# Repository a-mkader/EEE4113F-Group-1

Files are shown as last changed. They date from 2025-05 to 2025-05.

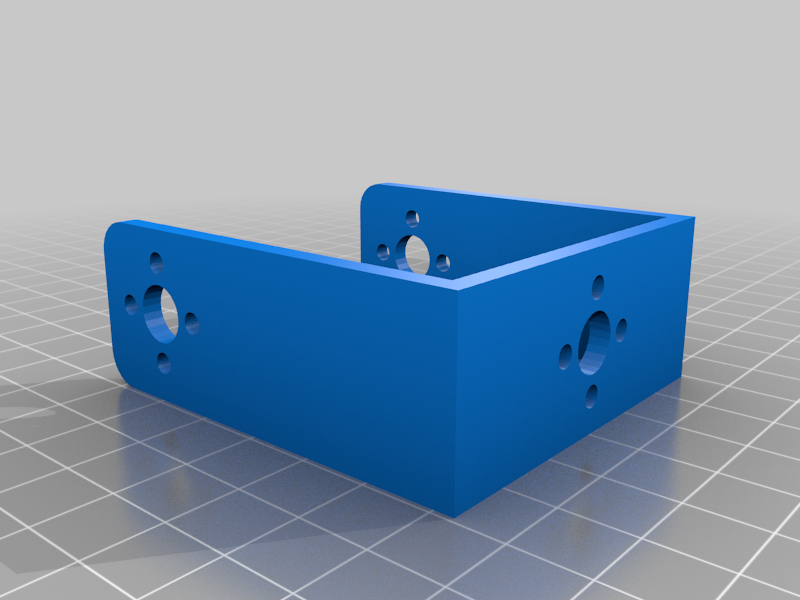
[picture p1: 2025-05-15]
Camera Tracking and Visual Deterrent/3D Designs/PAN-TILT SERVO MG995 - MG996 - DS3218 - 3458238/images/cf411c098905289544de61feb33862b2.png

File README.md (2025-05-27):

# 🐧 Humane Honey Badger Deterrent System  
**EEE4113F Final Year Project – Group 1 (2025)**  
University of Cape Town – Department of Electrical Engineering

## 📋 Overview

This repository contains the full implementation of a humane, AI-assisted deterrent system developed to protect endangered African penguins from honey badger predation. The project was completed as part of the EEE4113F Final Year Design course.

The system integrates real-time animal detection, a web-controlled tactile deterrent, and a visual tracking subsystem, all deployed on low-power, field-ready hardware.

---

## 🧠 Subsystems

### 1. Sensing & Identification 
- Passive infrared (PIR) sensors trigger image capture.
- A 5MP IR camera captures images upon motion detection.
- A TensorFlow Lite model classifies the image into:
  - `honey_badger`, `penguin`, `background`, or `other`
- Upon detecting a honey badger, a GPIO pin is triggered to activate deterrents.

### 2. Tactile Deterrent + Web UI 
- Raspberry Pi-controlled solenoid spray mechanism.
- React-based frontend and Flask backend.
- Features:
  - Manual calibration
  - Livestream from Pi camera
  - Log of past deterrents
  - Weather widget for ranger awareness

### 3. Visual Tracking Subsystem
- Pan-tilt servo system controlled by Raspberry Pi.
- Face detection via OpenCV.
- Flashing light deterrent to startle predators.
- Designed to enhance precision and reduce habituation.

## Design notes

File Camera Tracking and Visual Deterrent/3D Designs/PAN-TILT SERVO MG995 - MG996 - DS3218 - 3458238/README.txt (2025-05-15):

PAN-TILT SERVO MG995 - MG996 - DS3218 by VICTORHP7 on Thingiverse: https://www.thingiverse.com/thing:3458238

Summary:
PANT-TILT compatible with servos MG995 - MG996 - DS3218It works smooth!M310 screws are recommended. M312 will do it too.

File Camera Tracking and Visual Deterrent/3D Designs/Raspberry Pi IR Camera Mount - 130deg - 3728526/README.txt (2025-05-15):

Raspberry Pi IR Camera Mount - 130deg by Douglas_K on Thingiverse: https://www.thingiverse.com/thing:3728526

Summary:
This is borne of my not wanting to have a light on in the room when I'm printing.  So, I'm running an infrared camera with it's own lighting.  This is the one I used:Raspberry Pi 3 Night Vision Fisheye Camera 5MP OV5647 130 Degree Focal Adjustable Camera for Raspberry Pi 3 Model B Plushttps://www.aliexpress.com/item/32932807062.htmlThe main design I based this on, "Raspberry Pi IR Camera Mount" by MonkeyBear", had the correct openings for the lights, but they were too far apart.  A bit of a remix fixed that.  Then I used a bit from the "T-slot V-slot Universal camera mount :CR10, tevo tornado, ender 3 logitech c270 c920, picamera, gopro, action camera , prusa mk3, others" to add the mounting bit that's compatible with the bed mount I use with my Ender 3 Pro, "Ender 3 bed camera mount logitech c270,pi camera,gopro,action camera, holder(BETA TESTING finished)"It works a treat, as the 2nd image shows.:)This mount connects with this mount system which works well with the Creality Ender 3: https://www.thingiverse.com/thing:2999957

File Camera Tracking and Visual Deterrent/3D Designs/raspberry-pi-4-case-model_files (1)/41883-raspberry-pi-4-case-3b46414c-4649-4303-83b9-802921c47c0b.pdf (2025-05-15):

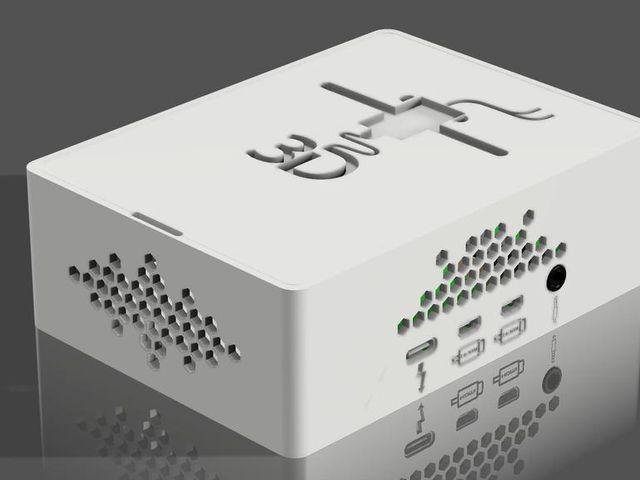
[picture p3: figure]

6.83 hrs

2 pcs

f

0.20 mm

k

0.40 mm

h

PLA

78 g

d

Prusa MINI /

MINI+

# Summary

A RaspBerry Pi 4 case designed to optimize the airflow around the board

and to keep it well cooled without the need of...

3D Printers (https://www.printables.com/model?categoryId=1) | > | Accessories (https://www.printables.com/model?categoryId=40)
Tags: case | raspberry | octoprint | octopi | 3dprinter
raspberrypi | raspberrypicase | octoprintcase

A RaspBerry Pi 4 case designed to optimize the airflow around the board

and to keep it well cooled without the need of a cooling fan.

From the hestetical point of view, it is recommended White PLA, but it can

be printed in any color you prefer.

Hope you enjoy it. If so, thumbs up and happy printing!

JayCee09 (https://www.printables.com/social/92276/about)

# RaspBerry Pi 4 case

VIEW IN BROWSER (https://www.printables.com/model/41883-raspberry-pi-4-case)

updated 12. 4. 2022 | published 9. 10. 2020

# Model files

## Print instructions Category: 3D Printer Accessories Summary

A RaspBerry Pi 4 case designed to optimize the airflow around the board

and to keep it well cooled without the need of a cooling fan.

From the hestetical point of view, it is recommended White PLA, but it can

be printed in any color you prefer.

Hope you enjoy it. If so, thumbs up and happy printing!

## Print Settings

### Rafts: No

### Supports: No

### Resolution: 0.2

## Infill: 25%

### Filament: Anycubic PLA White Notes:

Recommended at least 25% infill for the Lower case. The Upper case

doesn't require specified infill, while the infill for the Case cap is up to you

to decide.

For a better result, four screws M2.5x8 are recommended in order to keep

the board safely in place.

Take a look at these designes too:

Raspberry Pi 4B/Octoprint Honeycomb case da JayCee09 | Scarica il
modello STL gratuito | PrusaPrinters (https://www.prusaprinters.org/it/prints/44108-raspberry-pi-4boctoprint-honeycomb-case)

RaspberryPi 4B/Octoprint case and mount for Prusa MINI da JayCee09
| Scarica il modello STL gratuito | PrusaPrinters (https://www.prusaprinters.org/it/prints/118058-raspberrypi-4boctoprint-case-and-mount-for-prusa-m)

If you like this design, please consider buying me a coffee to support me in

the creation of many other useful designs as a sign of gratitude for the

huge amount of time and effort. Thank you very much and happy printing!

•

•

upper_case.stl

# Print files

h PLA | k 0.40 mm | f 0.20 mm | 1.47 hrs | 22 g | d Prusa MINI / MINI+
h PLA | k 0.40 mm | f 0.20 mm | 5.36 hrs | 56 g | d Prusa MINI / MINI+

Find source .stl files on Thingiverse.com (https://www.thingiverse.com/thing:4562146)

# License

This work is licensed under a

Creative Commons (4.0 International License)

Attribution (http://creativecommons.org/licenses/by/4.0/)

✖ | Sharing without ATTRIBUTION
✔ | Remix Culture allowed
✔ | Commercial Use
✔ | Free Cultural Works
✔ | Meets Open Definition

lower_case.stl

case_cap.stl

case-cap_02mm_pla_mini_1h28m.gcode

upperlower-case_02mm_pla_mini_5h21m.gcode

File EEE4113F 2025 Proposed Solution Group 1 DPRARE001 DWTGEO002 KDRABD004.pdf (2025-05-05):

Solution Statement and Subsystem Breakdown
Solution Statement
This project proposes a humane and integrated deterrent solution designed to protect penguin colonies from honey badgers. The approach combines real-time animal detection, automated species identification, and visual deterrents specifically flashing lights. By activating these visual deterrents only when a honey badger is positively identified, the system ensures minimal interference with penguins. This targeted strategy is intended to eectively discourage honey badger intrusions while maintaining a safe and undisturbed environment for the penguin population.

Subsystem Breakdown
The proposed solution is structured into three complementary subsystems, each managed by a specific team member:

### 1. Sensing Subsystem (Georgene de Wet)

The sensing subsystem will deploy motion detection sensors and thermal cameras strategically positioned along the existing penguin colony fence. The motion detection sensors provide energy-eicient, reliable detection of animal movement. To enhance accuracy, especially during night time or in challenging weather conditions, thermal cameras will detect the presence of animals through their unique heat signatures, reducing the likelihood of false detections due to environmental factors or penguins.

### 2. Software and Identification Subsystem (Arend Jacques du Preez)

This subsystem will be responsible for processing sensor data in real-time to distinguish honey badgers from penguins and other wildlife. Utilizing advanced, lightweight artificial intelligence and machine learning methods suitable for low-power hardware, this subsystem will rapidly and accurately classify the animals detected. Upon positive identification of a honey badger, the software subsystem will promptly signal the visual deterrent subsystem for activation.

### 3. Camera Tracking and Visual Deterrent Subsystem (Abdul-Mateen Kader)

The camera tracking subsystem will continuously track the movements of detected honey badgers outside the protected area, enabling precise targeting of deterrents. Once the presence of a honey badger is confirmed, this subsystem will activate flashing lights to immediately deter the animal. The visual deterrent is designed to provide eective repulsion without adversely aecting the natural behaviours and routines of penguins, ensuring ecological safety and sustained eectiveness.
Together, these subsystems form a comprehensive and humane strategy to eectively protect penguin habitats from honey badger intrusion while prioritizing ecological sensitivity and long-term reliability.

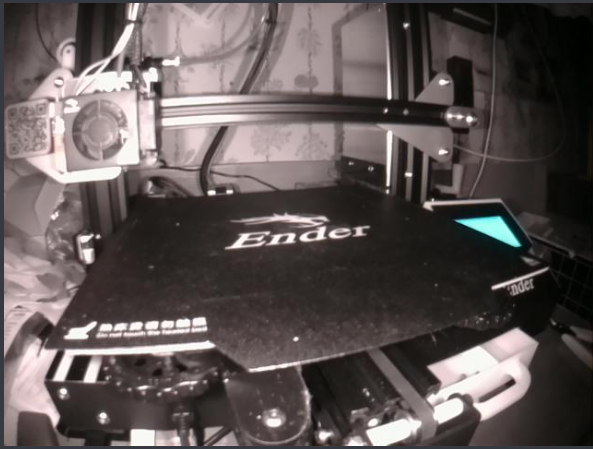
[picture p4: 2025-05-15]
Camera Tracking and Visual Deterrent/3D Designs/Raspberry Pi IR Camera Mount - 130deg - 3728526/images/IR_PiCam_Image.png

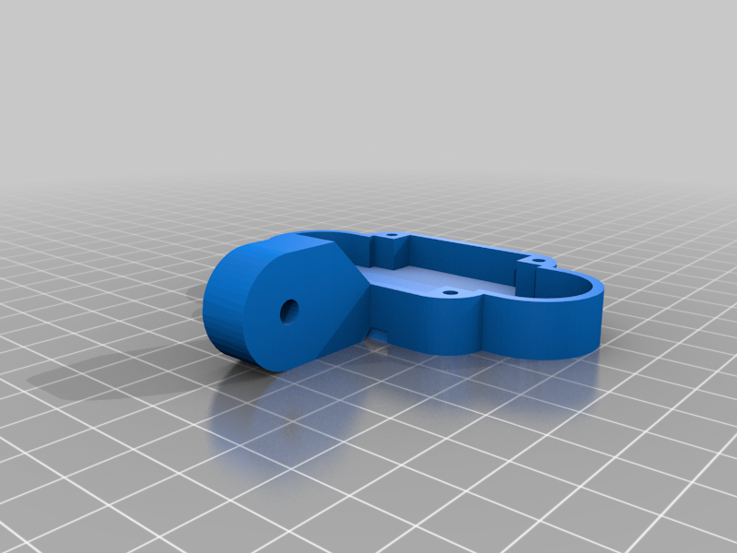
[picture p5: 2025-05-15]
Camera Tracking and Visual Deterrent/3D Designs/Raspberry Pi IR Camera Mount - 130deg - 3728526/images/b11e25e2dc768ef985b8156a6ab60719.png

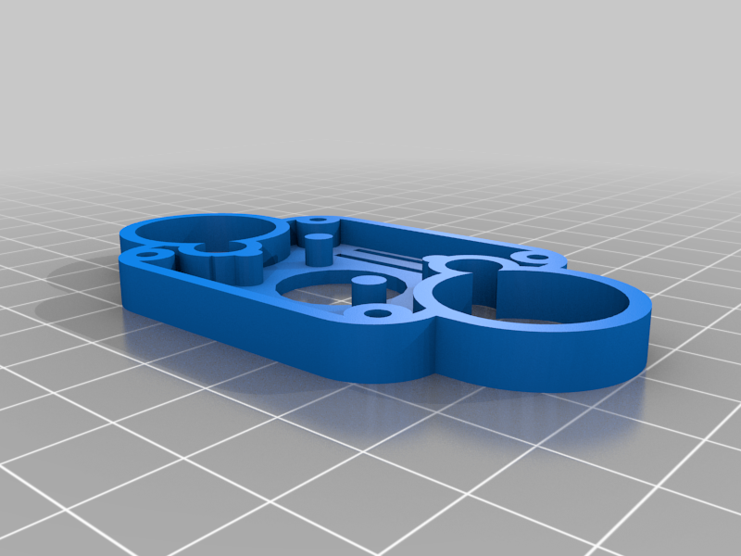
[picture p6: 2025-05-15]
Camera Tracking and Visual Deterrent/3D Designs/Raspberry Pi IR Camera Mount - 130deg - 3728526/images/88cf1d012a740bfe37dd442dfd6154a1.png

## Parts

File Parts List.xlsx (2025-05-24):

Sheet: Sheet1
Subsystem | Part | Unit Price | Quantity | Total | Link
Sensing |  | R 299.90 | 1 | R 299.90 | https://www.pishop.co.za/store/raspberry-pi-noir-infrared-camera-board-v2-8mp1080p
 | IR Illuminator 30M80DEG 12V T1 (surveillance illuminator)- Provides invisible light for night images | R 394.45 | 1 | R 394.45 | https://www.communica.co.za/collections/security-access-control-surveillance/ir-illuminators
 | SanDisk MicroSD Card 32GB | R 120.00 | 1 | R 120.00 | https://www.pricecheck.co.za/search?search=SanDisk+MicroSD+Card+32GB
 | HKD Digital PIR Motion Sensor (HC-SR501) | R 25.00 | 3 | R 75.00 | https://www.communica.co.za/products/hkd-digital-pir-motion-sensor
Tactile Detterent | BMT MINI SOLENOID LOCK 12V 0,35A | R 98.00 | 1 | R 98.00 | https://www.communica.co.za/products/bmt-mini-solenoid-lock-12v-0-35a-1?variant=44153786892588
Camera Tracking | Servo Driver Module | R 99.00 | 1 | R 99.00 | https://www.takealot.com/robotico-16-channel-12-bit-pwm-servo-motor-driver-i2c-module-rob/PLID92827099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
 | 12-5V Converter | R 43.00 | 2 | R 42.00 | https://www.communica.co.za/products/hkd-adj-dc-dc-module-3a-display?variant=39359978963017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
 | Micro Servos | R 55.00 | 2 | R 110.00 | https://www.communica.co.za/products/cmu-servo-motor-mg996r-11kg-180d
 | LED | R 49.00 | 2 | R 98.00 | https://www.communica.co.za/products/bdd-rect-power-led-white-10w-12v?variant=47484297576748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
 |  |  | Total | R 1336.35
For Tactile Detterent
CMU STEPPER MOTOR 4 PHASE 12V | https://www.communica.co.za/products/cmu-stepper-motor-4-phase-12v
HKD STEPPER EASY DRIVER A3967 | https://www.communica.co.za/products/hkd-stepper-easy-driver-a3967?variant=31916107825225
BMT MINI SOLENOID LOCK 12V 0,35A | https://www.communica.co.za/products/bmt-mini-solenoid-lock-12v-0-35a-1?variant=44153786892588

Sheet: Sheet2
Part | Quantity | Price
PIR Sensor | 3 | R 25.00
Voltage Relay | 1 | R 65.00
Solenoid Valve | 1 | R 98.00
Epoxy | 1 | R 155.00
Raspberry Pi 4B | 1 | R 1512.00
SanDisk MicroSD Card 32GB | 1 | R 120.00
HKD 5MP IR Camera | 1 | R 399.00
50cm Camera Extension Cable | 1 | R 37.00
MG995 Servo Motor | 2 | R 55.00
PCA9685 Servo Driver Module | 1 | R 99.00
10W Power LED | 1 | R 49.00
DC/DC Module | 1 | R 42.00
1.5 ohm Resistor | 1 | R 0.35
1k ohm Resistor | 1 | R 3.40
1x40 2.54mm Pin Headers | 4 | R 6.90
TIP41C Transistor | 1 | R 7.99
15cm M/M Jumper Cables | 40 | R 20.00
15cm M/F Jumper Cables | 40 | R 20.00
15cm F/F Jumper Cables | 40 | R 20.00
3M Nuts | 25 | R 0.54
3M Bolts | 25 | R 1.54
4mm Self Tapping Screws | 25 | R 0.22
3D Printer Filament (g) | 303.13 | R 0.30

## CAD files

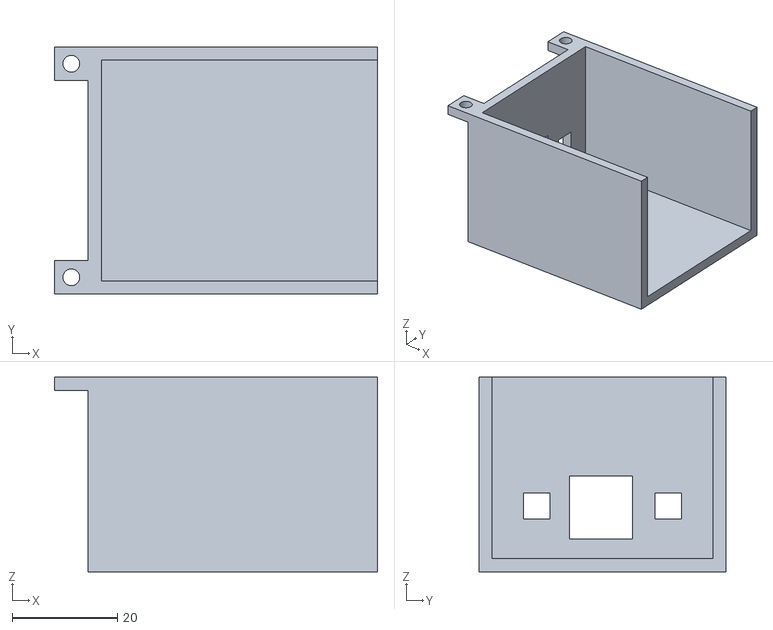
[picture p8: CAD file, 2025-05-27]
Camera Tracking and Visual Deterrent/3D Designs/Final STLs/Light Housing/Main v1.stl
61.4 x 47.0 x 37.0

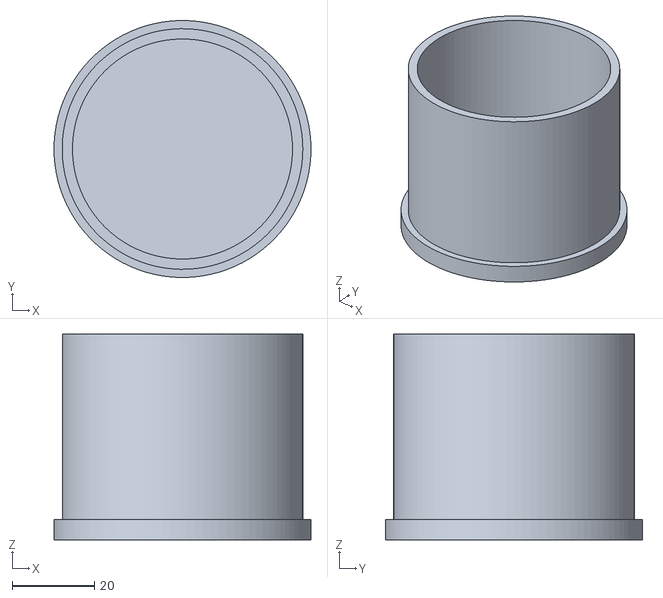
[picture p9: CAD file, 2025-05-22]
Camera Tracking and Visual Deterrent/3D Designs/Final STLs/Can Mount v2.stl
62.5 x 62.4 x 50.0

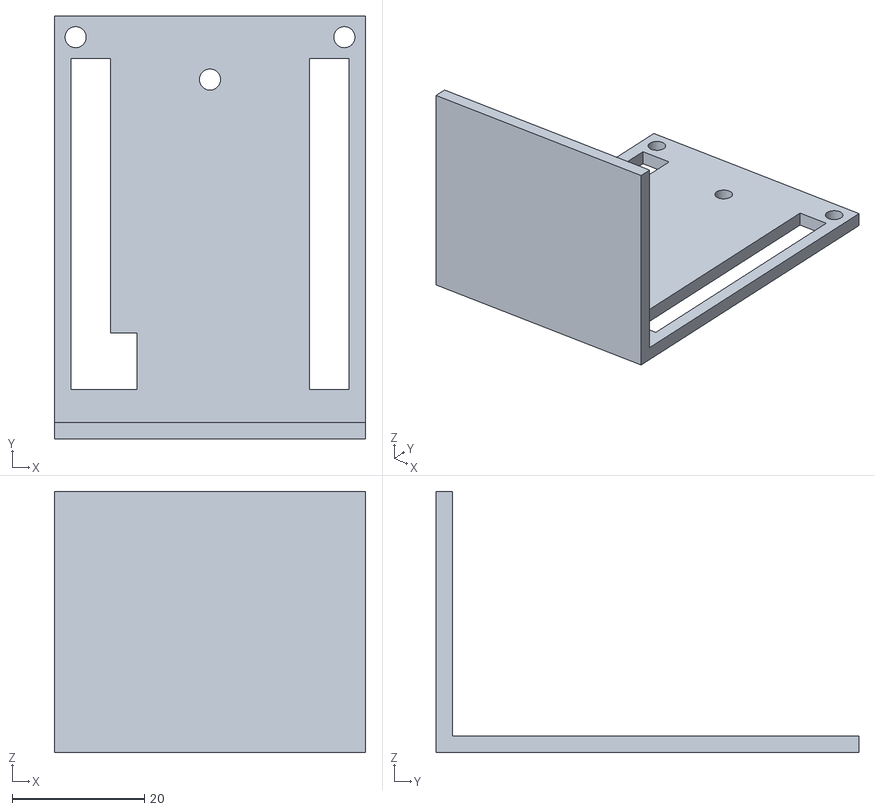
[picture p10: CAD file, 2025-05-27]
Camera Tracking and Visual Deterrent/3D Designs/Final STLs/Light Housing/Lighting Lid v4.stl
47.0 x 63.9 x 39.5

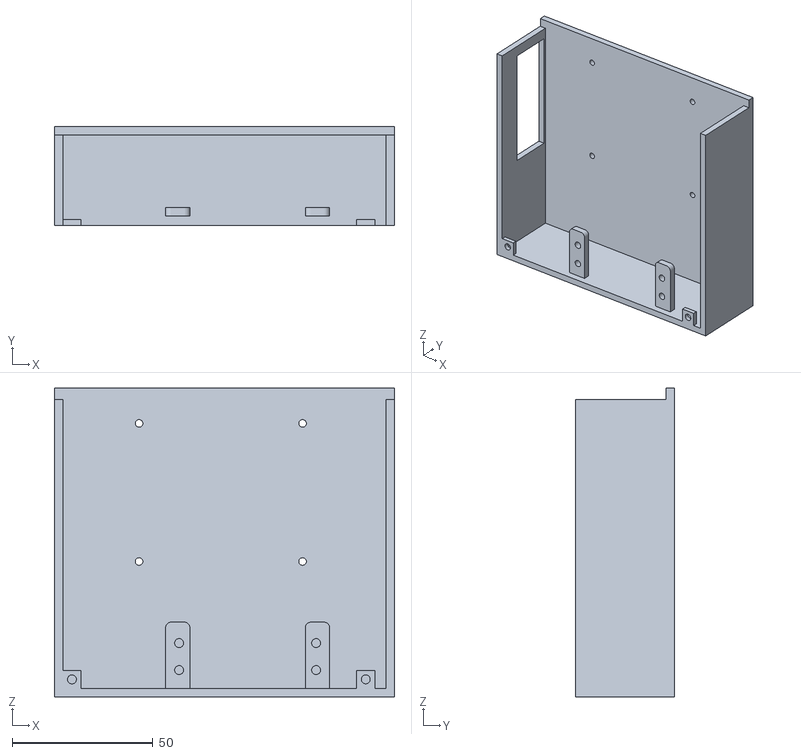
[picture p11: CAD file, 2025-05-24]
Camera Tracking and Visual Deterrent/3D Designs/Final STLs/Pan-Tilt Mechanism/Base Servo Housing v8.stl
120.6 x 35.0 x 109.5

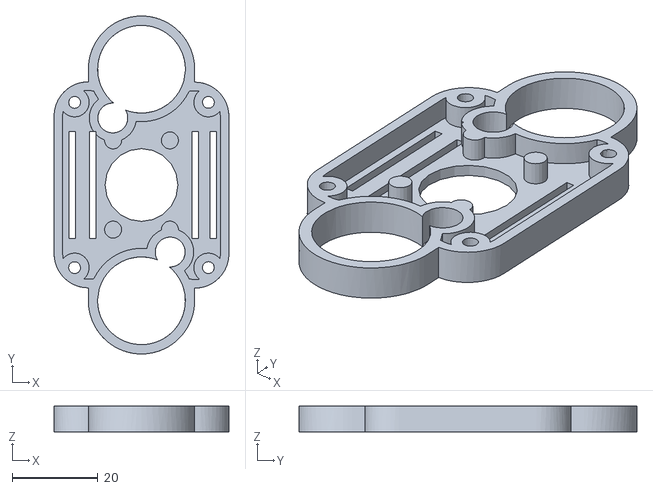
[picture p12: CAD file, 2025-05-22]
Camera Tracking and Visual Deterrent/3D Designs/Final STLs/Pi Camera Case/Camera Body v1.stl
40.9 x 79.0 x 6.00

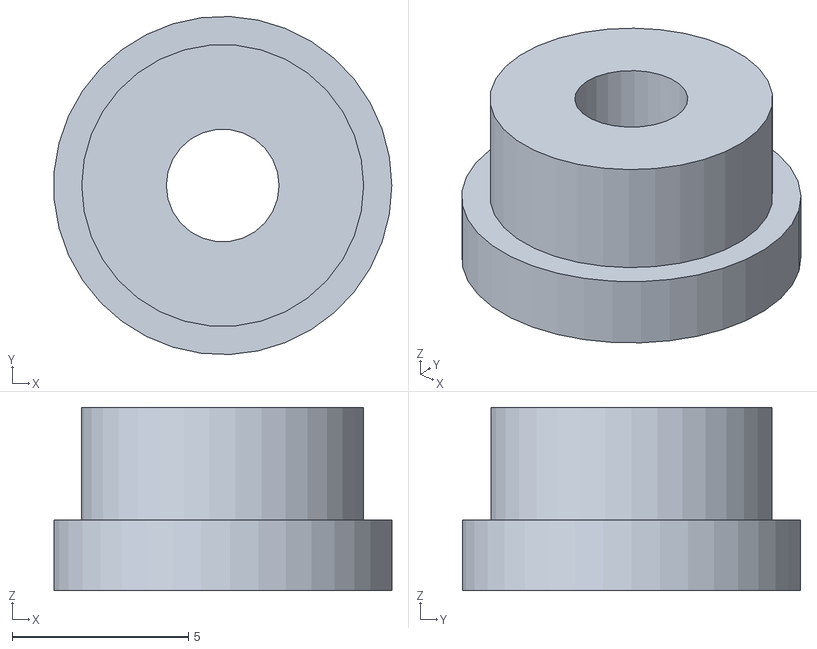
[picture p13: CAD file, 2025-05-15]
Camera Tracking and Visual Deterrent/3D Designs/PAN-TILT SERVO MG995 - MG996 - DS3218 - 3458238/files/PAN-TILT_ROTOR_V2.stl
9.58 x 9.59 x 5.20

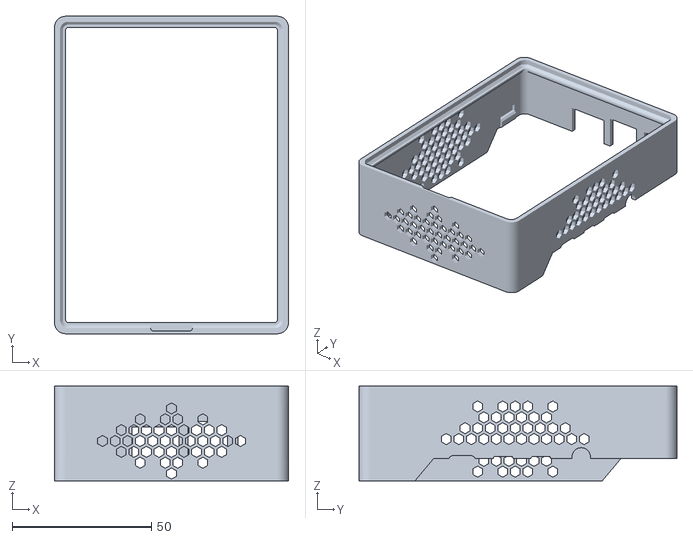
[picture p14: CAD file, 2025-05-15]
Camera Tracking and Visual Deterrent/3D Designs/raspberry-pi-4-case-model_files (1)/upper_case.stl
84.0 x 114.0 x 34.0

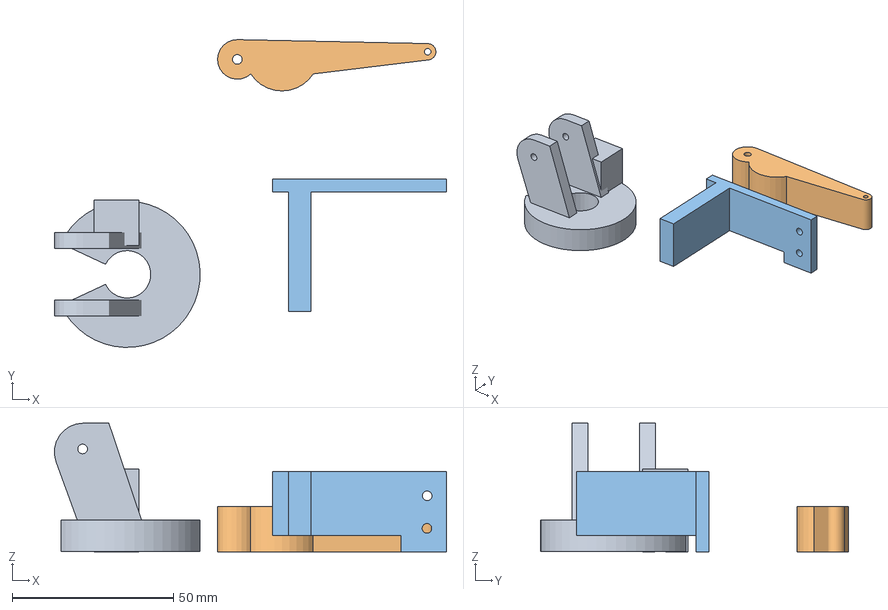
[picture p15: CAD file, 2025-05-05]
Tactile Deterrent/Printing3D Design Group 1 tactile detterent .3mf
121.7 x 95.5 x 39.9 mm
bracket.stl
trigger.stl
Body1.stl

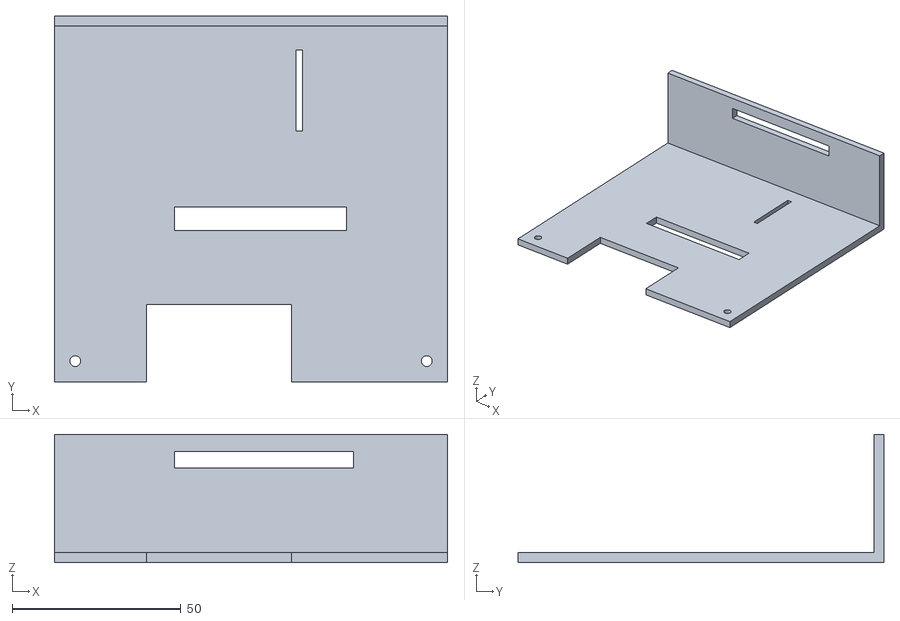
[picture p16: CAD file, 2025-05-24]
Camera Tracking and Visual Deterrent/3D Designs/Final STLs/Pan-Tilt Mechanism/Base Lid v5.stl
116.6 x 108.5 x 38.0

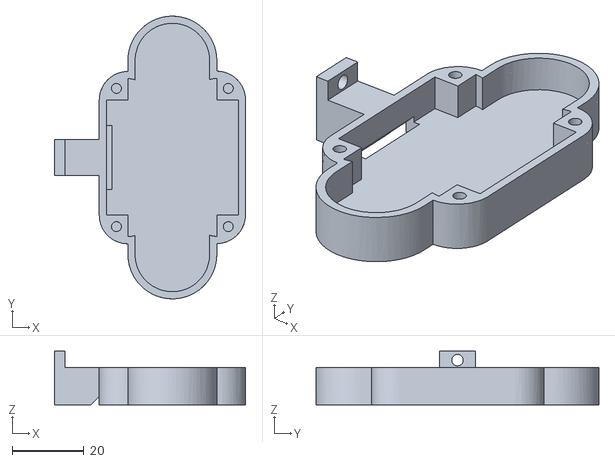
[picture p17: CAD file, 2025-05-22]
Camera Tracking and Visual Deterrent/3D Designs/Final STLs/Pi Camera Case/Camera Back v2.stl
53.4 x 79.0 x 15.0

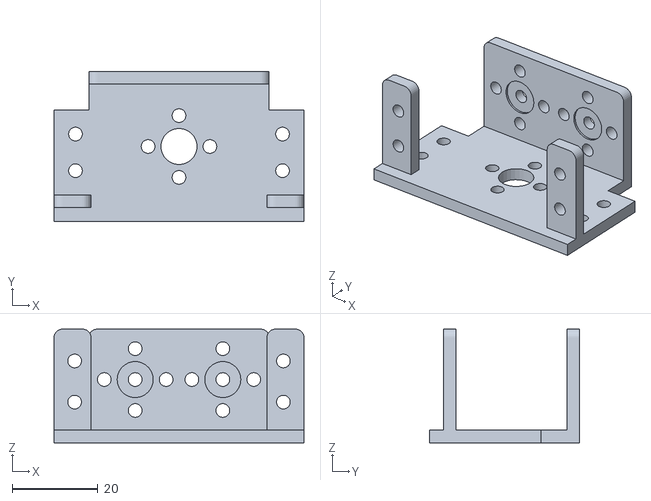
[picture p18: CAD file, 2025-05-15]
Camera Tracking and Visual Deterrent/3D Designs/PAN-TILT SERVO MG995 - MG996 - DS3218 - 3458238/files/PAN-TILT_BASE_V1.stl
58.2 x 35.0 x 26.5

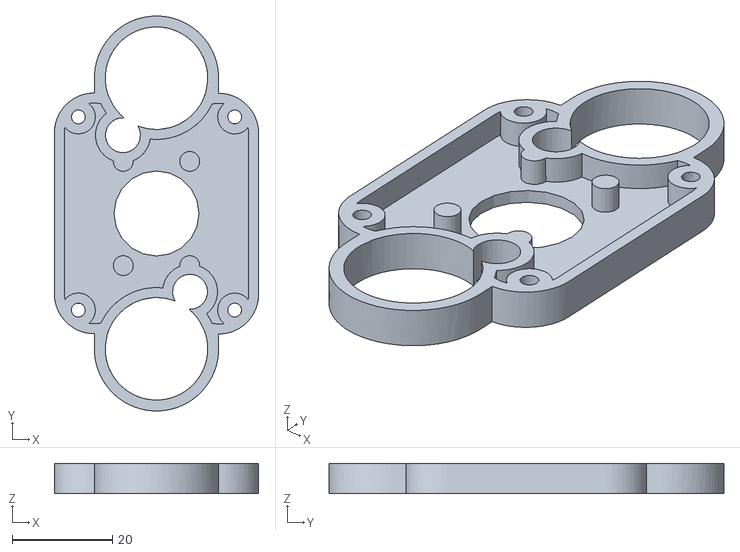
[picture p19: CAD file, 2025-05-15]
Camera Tracking and Visual Deterrent/3D Designs/Raspberry Pi IR Camera Mount - 130deg - 3728526/files/Pi_Camera_Mount_-_IR_-_Body.stl
40.9 x 79.0 x 6.00

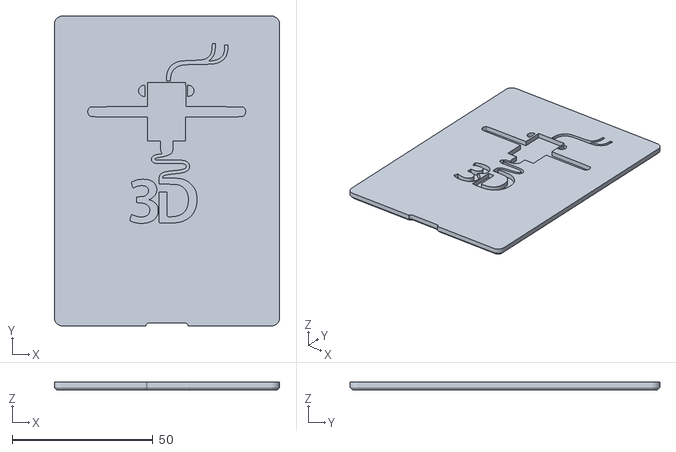
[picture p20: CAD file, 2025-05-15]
Camera Tracking and Visual Deterrent/3D Designs/raspberry-pi-4-case-model_files (1)/case_cap.stl
80.0 x 110.0 x 3.00

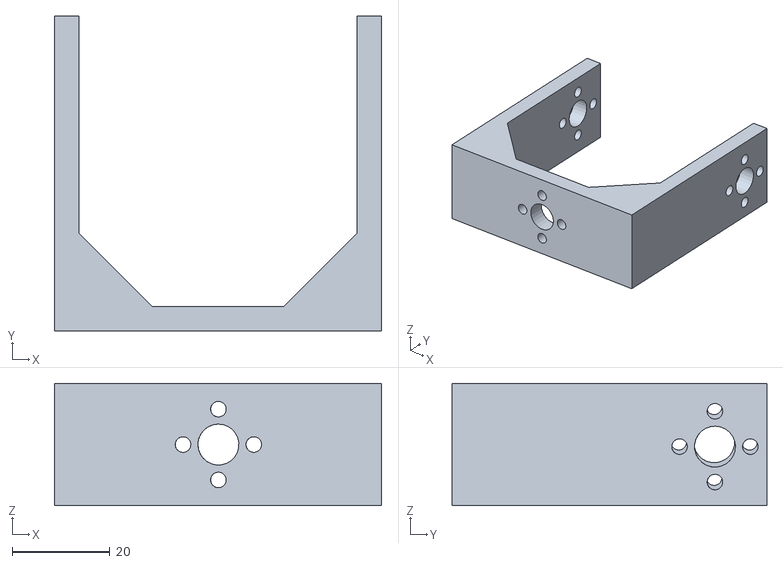
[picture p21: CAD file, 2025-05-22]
Camera Tracking and Visual Deterrent/3D Designs/Final STLs/Pan-Tilt Mechanism/Uprights v3.stl
67.0 x 64.5 x 25.0

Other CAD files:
Camera Tracking and Visual Deterrent/3D Designs/Raspberry Pi IR Camera Mount - 130deg - 3728526/files/Pi_Camera_Mount_-_IR_-_Front_-_Vented.stl
Tactile Deterrent/Printing3D Design.3mf
Camera Tracking and Visual Deterrent/3D Designs/PAN-TILT SERVO MG995 - MG996 - DS3218 - 3458238/files/PAN-TILT_LEG_V2.stl
Camera Tracking and Visual Deterrent/3D Designs/Raspberry Pi IR Camera Mount - 130deg - 3728526/files/Pi_Camera_Mount_-_IR_-_Back_-_vented.stl
Camera Tracking and Visual Deterrent/3D Designs/Final STLs/Pan-Tilt Mechanism/Tilt Servo Housing v7.stl
Camera Tracking and Visual Deterrent/3D Designs/Raspberry Pi IR Camera Mount - 130deg - 3728526/files/Pi_Camera_Mount_-_IR_-_Back.stl
Camera Tracking and Visual Deterrent/3D Designs/raspberry-pi-4-case-model_files (1)/lower_case.stl

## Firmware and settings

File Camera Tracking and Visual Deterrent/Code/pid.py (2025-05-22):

# pid.py
class PID:
    def __init__(self, Kp=1.0, Ki=0.0, Kd=0.0, output_limits=(0, 180)):
        self.Kp = Kp
        self.Ki = Ki
        self.Kd = Kd
        self.min_output, self.max_output = output_limits

        self.integral = 0
        self.prev_error = 0
        self.prev_time = None

    def compute(self, error, current_time):
        if self.prev_time is None:
            self.prev_time = current_time
            return 0

        dt = current_time - self.prev_time
        self.prev_time = current_time

        if dt <= 0.0:
            return 0

        # PID terms
        self.integral += error * dt
        derivative = (error - self.prev_error) / dt
        self.prev_error = error

        output = (self.Kp * error) + (self.Ki * self.integral) + (self.Kd * derivative)

        # Clamp output to limits with anti-windup
        if output > self.max_output:
            output = self.max_output
            # Undo last integral addition to prevent windup
            self.integral -= error * dt
        elif output < self.min_output:
            output = self.min_output
            self.integral -= error * dt

        return output

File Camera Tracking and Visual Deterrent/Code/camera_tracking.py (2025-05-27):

import cv2
import time
import threading
import subprocess
import os
import signal
from adafruit_servokit import ServoKit
from sshkeyboard import listen_keyboard, stop_listening
from pid import PID

def setup_virtual_camera():
    # Remove any existing loopback
    subprocess.run(["sudo", "modprobe", "-r", "v4l2loopback"], stderr=subprocess.DEVNULL)

    # Reload with proper caps (must include 'exclusive_caps=1', but also output capability!)
    subprocess.run([
        "sudo", "modprobe", "v4l2loopback",
        "video_nr=30",
        "card_label=VirtualCam",
        "exclusive_caps=1",
        "max_buffers=2"
    ])

    # Let the kernel register /dev/video30
    time.sleep(2)

    # Start GStreamer to pipe to /dev/video30
    gst_cmd = (
        "gst-launch-1.0 -v libcamerasrc ! "
        "video/x-raw,width=640,height=480,framerate=30/1 ! "
        "videoconvert ! "
        "video/x-raw,format=YUY2 ! "
        "queue ! "
        "v4l2sink device=/dev/video30"
    )

    return subprocess.Popen(gst_cmd, shell=True, preexec_fn=os.setsid)

    
def start_mediamtx():
    return subprocess.Popen(
        ["./mediamtx"],
        stdout=subprocess.DEVNULL,
        stderr=subprocess.DEVNULL,
        preexec_fn=os.setsid
    )

# ----------- Setup Stage -------------
gst_proc = setup_virtual_camera()
# Start MediaMTX
mediamtx_proc = subprocess.Popen(["./mediamtx"], stdout=subprocess.DEVNULL, stderr=subprocess.DEVNULL)
time.sleep(3)  # Allow time for /dev/video30

cv2.setUseOptimized(True)
kit = ServoKit(channels=16)
pan_angle = 90
tilt_angle = 90
kit.servo[0].angle = pan_angle
kit.servo[1].angle = tilt_angle

pan_pid = PID(Kp=1.5, Ki=0.025, Kd=0.5, output_limits=(-5, 5))
tilt_pid = PID(Kp=1.5, Ki=0.025, Kd=0.5, output_limits=(-5, 5))

release_a = release_d = release_w = release_s = False
loop = True

def press(key):
    global loop, pan_angle, tilt_angle, release_a, release_d, release_w, release_s
    if key == 'q':
        loop = False
    if key == "w":
        release_w = False
        while tilt_angle > 15 and not release_w:
            tilt_angle -= 1
            kit.servo[1].angle = tilt_angle
            time.sleep(0.01)
    elif key == "s":
        release_s = False
        while tilt_angle < 180 and not release_s:
            tilt_angle += 1
            kit.servo[1].angle = tilt_angle
            time.sleep(0.01)
    elif key == "a":
        release_a = False
        while pan_angle < 180 and not release_a:
            pan_angle += 1
            kit.servo[0].angle = pan_angle
            time.sleep(0.01)
    elif key == "d":
        release_d = False
        while pan_angle > 0 and not release_d:
            pan_angle -= 1
            kit.servo[0].angle = pan_angle
            time.sleep(0.01)

def release(key):
    global release_a, release_d, release_w, release_s
    if key == "w": release_w = True
    elif key == "s": release_s = True
    elif key == "a": release_a = True
    elif key == "d": release_d = True

keyboard_thread = threading.Thread(target=lambda: listen_keyboard(on_press=press, on_release=release, delay_second_char=0.001))
keyboard_thread.daemon = True
keyboard_thread.start()

cap = cv2.VideoCapture("/dev/video30")
ret, img = cap.read()
if not ret:
    print("Failed to grab first frame.")
    gst_proc.terminate()
    start_mediamtx()
    exit(1)

res = (256, 144) if img.shape[1]/img.shape[0] > 1.55 else (216, 162)
scale_factor = 3
XC = res[0] / 2
YC = res[1] * 7 / 16

vcam_writer = cv2.VideoWriter('/dev/video30', cv2.VideoWriter_fourcc(*'MJPG'), 30, res)

# Start RTSP streaming using FFmpeg to MediaMTX
stream_proc = subprocess.Popen(
    [
        'ffmpeg',
        '-y',
        '-f', 'rawvideo',
        '-pix_fmt', 'bgr24',
        '-s', f'{res[0]}x{res[1]}',
        '-r', '30',
        '-i', '-',
        '-c:v', 'libx264',
        '-preset', 'ultrafast',
        '-f', 'rtsp',
        'rtsp://localhost:8554/cam'
    ],
    stdin=subprocess.PIPE
)

cascade = cv2.CascadeClassifier("haarcascades/haarcascade_frontalface_default.xml")

frame_interval = 0.05
last_time = time.time()
frame_count = 0
detect_interval = 1
show_window = True

while loop:
    ret, img = cap.read()
    if not ret:
        print("Failed to grab frame.")
        time.sleep(0.1)
        continue

    now = time.time()
    if now - last_time < frame_interval:
        continue
    last_time = now
    frame_count += 1

    resized = cv2.resize(img, res, interpolation=cv2.INTER_AREA)
    gray = cv2.cvtColor(resized, cv2.COLOR_BGR2GRAY)

    # --- Detect face ---
    if frame_count % detect_interval == 0:
        faces = cascade.detectMultiScale(gray)
    else:
        faces = []

    # --- If face found, track ---
    if len(faces) > 0:
        x, y, w, h = faces[0]
        center = (x + w / 2, y + h / 2)
        pan_error = XC - center[0]
        tilt_error = YC - center[1]

        pan_adjust = pan_pid.compute(pan_error, now) if abs(pan_error) > 15 else 0
        tilt_adjust = tilt_pid.compute(tilt_error, now) if abs(tilt_error) > 15 else 0

        pan_angle = max(0, min(180, pan_angle + pan_adjust))
        tilt_angle = max(0, min(180, tilt_angle + tilt_adjust))
        kit.servo[0].angle = pan_angle
        kit.servo[1].angle = tilt_angle

        if show_window:
            cv2.rectangle(resized, (x, y), (x + w, y + h), (0, 255, 0), 1)

        print(f"pan_error: {pan_error:.2f}, pan_adjust: {pan_adjust or 0:.2f}, pan_angle: {pan_angle:.2f}")
        print(f"tilt_error: {tilt_error:.2f}, tilt_adjust: {tilt_adjust or 0:.2f}, tilt_angle: {tilt_angle:.2f}")


    else:
        if show_window:
            cv2.putText(resized, "No face detected", (10, res[1] - 10), cv2.FONT_HERSHEY_SIMPLEX, 0.5, (0,0,255), 1)

    # --- Write to BOTH RTSP and Virtual Cam ---
    stream_proc.stdin.write(resized.tobytes())
    vcam_writer.write(resized)

    # --- Show preview window ---
    if show_window:
        display_img = cv2.resize(resized, (res[0]*scale_factor, res[1]*scale_factor), interpolation=cv2.INTER_NEAREST)
        cv2.imshow("Face Tracker", display_img)
        if cv2.waitKey(1) & 0xFF == ord('q'):
            loop = False

# ----------- Cleanup -------------
cap.release()
cv2.destroyAllWindows()
stop_listening()
keyboard_thread.join()
vcam_writer.release()
os.killpg(os.getpgid(gst_proc.pid), signal.SIGTERM)
stream_proc.terminate()
mediamtx_proc.terminate()
print("Exiting")

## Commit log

2025-05-05 Git created
    [BOTTOM+BODY.f3d, Parts List.xlsx, TOP+BODY.f3d]
2025-05-15 Top servo housing and uprights adjusted
    [Camera Mount Component V2 - Base Holder.stl, Camera Mount Component V2 - PCB Holder.stl, Camera Mount Component V2 - Pan Holder.stl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]
2025-05-22 Big commit, main thing is camera tracking code
    [Base Lid v3.stl, Base Servo Housing v4.stl, Body v1.stl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]
2025-05-23 Edited STL and print gcode
    [Base Lid v3.stl, Base Servo Housing v4.stl, Base Servo Housing v6.stl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]
2025-05-24 Cleaned up repo
    [BOTTOM+BODY.f3d, Base Lid v3.stl, Base Lid v5.stl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]
2025-05-27 Gains tuned, increased deadzone
    [BOTTOM+BODY.f3d, Base Lid v3.stl, Base Lid v5.stl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]
